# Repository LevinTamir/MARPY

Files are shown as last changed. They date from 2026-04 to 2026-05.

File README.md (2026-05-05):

<p align="center">
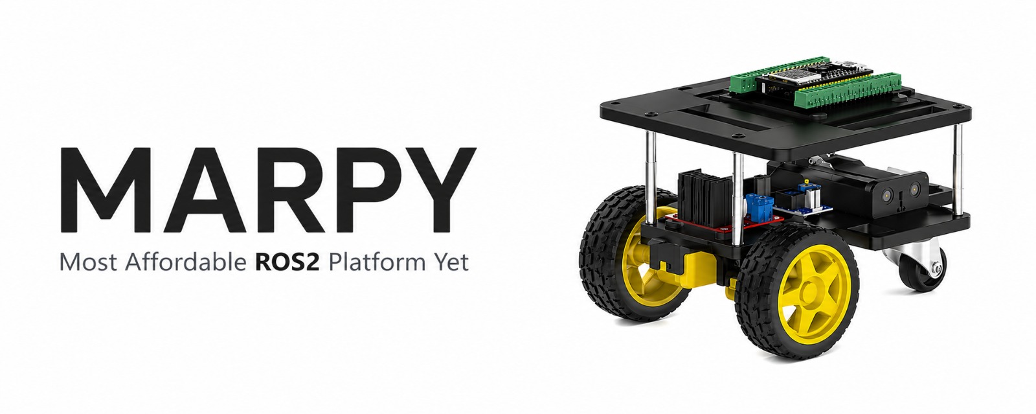
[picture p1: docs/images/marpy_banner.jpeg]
MARPY - Most Affordable ROS2 Platform Yet
  
</p>

<div align="center">

   

</div>

A cheap, open-source, 3D-printed differential-drive robot designed for beginners who want to learn ROS2 with real hardware.

---

## Requirements

- Ubuntu 24.04
- ROS2 Jazzy (or Docker)
- PlatformIO (for flashing the ESP32)
- A 2.4 GHz WiFi network the PC and the ESP32 boards can both join. A mobile phone hotspot works well (verified on iOS); the ESP32 does not support 5 GHz, so make sure the hotspot is on 2.4 GHz.

## Quick Start

### 1. Clone the workspace

```bash
git clone https://github.com/LevinTamir/MARPY.git marpy_ws
cd marpy_ws
```

### 2. Build the robot

Follow the guides in order:

| Step | Guide | Description |
|---|---|---|
| 1 | [Bill of Materials](docs/bom.md) | Buy the parts (< 50$) |
| 2 | [Assembly Instructions](docs/assembly.md) | Build the robot |
| 3 | [Wiring Guide](docs/wiring.md) | Connect all the electronics |
| 4 | [Firmware Setup](docs/firmware-setup.md) | Flash the ESP32 with micro-ROS |
| 5 | [ROS2 Setup](docs/ros2-setup.md) | Set up your PC and start driving! |
| 6 | [Simulation](docs/simulation.md) | Run MARPY in Gazebo (no hardware needed) |

### 3. Drive!

```bash
# Terminal 1: Start the micro-ROS agent
docker run -it --rm --net=host microros/micro-ros-agent:jazzy udp4 --port 8888 -v6

# Terminal 2: Launch the real robot (robot_state_publisher, odometry, RViz)
ros2 launch marpy_bringup real.launch.py

# Terminal 3: Drive with keyboard teleop
sudo apt install ros-jazzy-teleop-twist-keyboard
ros2 run teleop_twist_keyboard teleop_twist_keyboard
```

## Demos

**Real robot:**

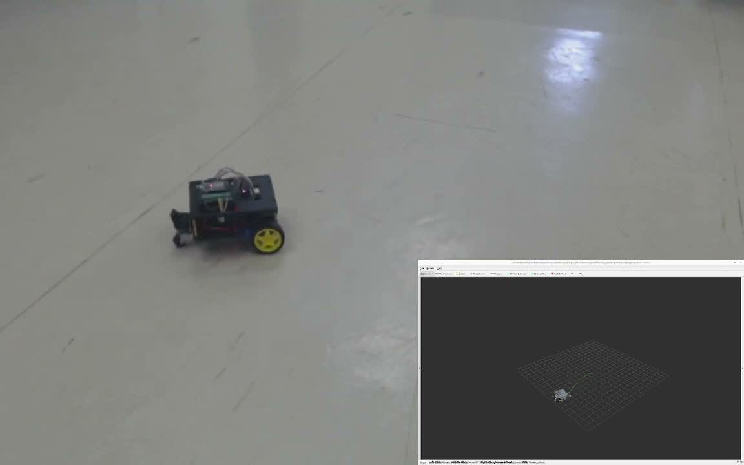
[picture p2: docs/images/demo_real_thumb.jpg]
MARPY real robot demo (https://youtu.be/ZrNPOut3CuA)


**Simulation:**

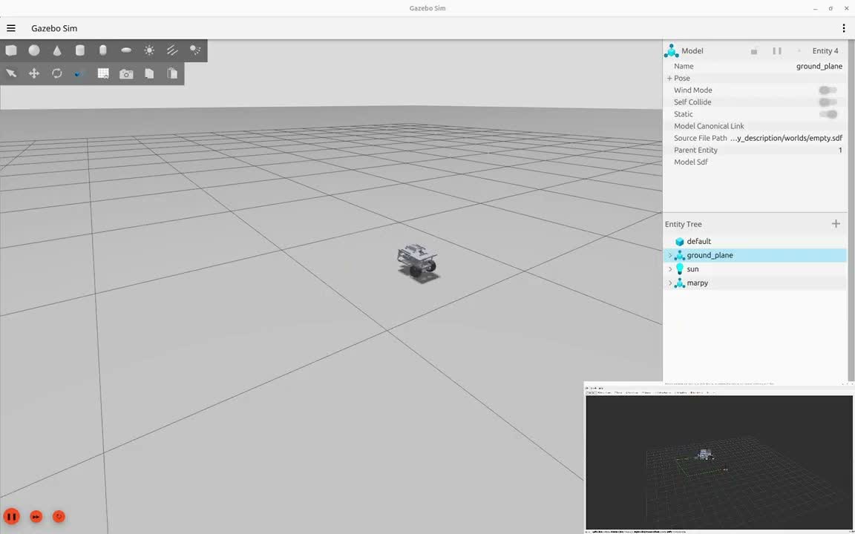
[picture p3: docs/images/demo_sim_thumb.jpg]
MARPY simulation demo (https://youtu.be/tEwZcNDOt3I)


## Repository Structure

```
marpy_ws/
├── README.md               ← You are here
├── docs/
│   ├── bom.md              ← Bill of materials + purchase links
│   ├── assembly.md         ← Step-by-step build guide
│   ├── wiring.md           ← Wiring diagram + pin tables
│   ├── firmware-setup.md   ← Flash the ESP32
│   ├── ros2-setup.md       ← ROS2 + micro-ROS agent setup
│   └── images/             ← Robot photos and diagrams
├── src/
│   ├── marpy_description/  ← URDF model + meshes + Gazebo worlds
│   ├── marpy_localization/ ← Wheel odometry + path tracking
│   └── marpy_bringup/      ← Launch files (sim + real)
├── docker/
│   ├── docker-compose.yml  ← micro-ROS agent + dev container
│   ├── Dockerfile          ← ROS2 Jazzy dev environment
│   └── entrypoint.sh
└── .github/workflows/      ← CI/CD pipeline
```

## Firmware Repositories

The ESP32 firmware lives in two separate repos:

- **[marpy_firmware](https://github.com/LevinTamir/marpy_firmware)** - PlatformIO project for the ESP32 drive controller: micro-ROS, motor control, encoder reading, and IMU.
- **[marpy_cam_firmware](https://github.com/LevinTamir/marpy_cam_firmware)** *(optional)* - PlatformIO project for the ESP32-CAM: serves an MJPEG stream over HTTP, republished as `sensor_msgs/Image` by the `marpy_cam_bridge` node.

## Contributing

Contributions are welcome! If you build a MARPY robot, open an issue with photos so everyone can see it.

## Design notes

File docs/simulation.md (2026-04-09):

# Simulation

Run MARPY in Gazebo Ignition without any hardware. The simulation uses the same `/cmd_vel` and `/joint_states` topics as the real robot, so teleop and odometry work identically.

## Prerequisites

Install the following ROS2 Jazzy packages (Ubuntu 24.04):

```bash
sudo apt update
sudo apt install -y \
  ros-jazzy-ros-gz-sim \
  ros-jazzy-ros-gz-bridge \
  ros-jazzy-robot-state-publisher \
  ros-jazzy-xacro \
  ros-jazzy-rviz2 \
  ros-jazzy-teleop-twist-keyboard
```

Build the workspace:

```bash
cd ~/marpy_ws
colcon build --symlink-install
source install/setup.bash
```

## Launch the Simulation

The `sim.launch.py` file starts Gazebo, RViz, and the odometry node in one command:

```bash
ros2 launch marpy_bringup sim.launch.py
```

This launches:
- **Gazebo Ignition** with the MARPY robot spawned in an empty world
- **RViz** for visualization (TF, robot model, odometry path)
- **Odometry node** computing wheel odometry from `/joint_states`

## Drive the Robot

In a separate terminal:

```bash
source ~/marpy_ws/install/setup.bash
ros2 run teleop_twist_keyboard teleop_twist_keyboard
```

Use the keyboard to drive. You should see:
- The robot moving in Gazebo
- The odometry path (`/odom_path`) drawing in RViz
- The TF tree updating in real time

## Visualize the Odometry Path in RViz

If the path is not already visible in RViz:

1. Click **Add** in the Displays panel
2. Select **By topic** → `/odom_path` → **Path**
3. Click **OK**

The path will draw the route the robot has traveled in the odom frame.

## View the URDF Model Only

To inspect the robot model in RViz without Gazebo:

```bash
ros2 launch marpy_description display.launch.py
```

## Custom Worlds

Pass a custom world file:

```bash
ros2 launch marpy_bringup sim.launch.py world_name:=my_world
```

World files are located in `src/marpy_description/worlds/` (SDF format).

## Troubleshooting

**Gazebo doesn't start or hangs:**
```bash
pkill -9 -f "gz sim|rviz2|robot_state_publisher|parameter_bridge"
```
Then relaunch.

**Robot doesn't move with teleop:**
- Make sure the teleop terminal is focused (it reads keypresses)
- Check that the Gazebo bridge is running: `ros2 topic list` should show `/cmd_vel`

**No odometry path in RViz:**
- Verify the odometry node is running: `ros2 node list` should show `/odometry_node`
- Check the topic: `ros2 topic echo /odom_path --once`

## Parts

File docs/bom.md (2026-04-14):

# Bill of Materials (BOM)

Everything you need to build your own MARPY robot. Total cost is approximately **$40-55 USD** depending on what you already have.

## Electronics

| # | Component | Qty | Est. Price | Link |
|---|---|-----|---|---|
| 1 | ESP32 DevKit V1 (30-pin) with Screw Terminal Breakout Board | 1 | ~$10 | [Amazon](https://www.amazon.com/dp/B0BNQ8VQDX) |
| 2 | L298N Dual H-Bridge Motor Driver | 1 | ~$3 | [Amazon](https://a.co/d/04wIWBpv) |
| 3 | TT Encoder Motor (6V DC Gear Motor with Hall Encoder) | 2 | ~$12 | [Amazon](https://www.amazon.com/dp/B0GS97898M) |
| 4 | 65mm TT Motor Wheels | 2 | ~$3 | [Amazon](https://www.amazon.com/dp/B0CG1C7T8J) |
| 5 | Low Profile Plastic Caster Wheel (1") | 1 | ~$3 | [Amazon](https://a.co/d/03JeFDlU) |
| 6 | 18650 Li-Ion Battery (3.7V, 2600mAh+) | 2 | ~$5 | [Amazon](https://www.amazon.com/dp/B0FP2DPJK7) |
| 7 | 2S 18650 Battery Holder with Switch | 1 | ~$3 | [Amazon](https://www.amazon.com/dp/B09ZPCX9VD) |
| 8 | LM2596S Adjustable DC-DC Buck Converter (7-28V to 5V) | 1 | ~$2 | [Amazon](https://a.co/d/05IxwOWH) |
| 9 | MPU6050 IMU (6-axis accelerometer + gyroscope) | 1 | ~$2 | [Amazon](https://www.amazon.com/dp/B00LP25V1A) |
| 10 | Jumper Wires | 1 kit | ~$3 | [Amazon](https://www.amazon.com/dp/B077NH83CJ) |
| 11 | Micro-USB Cable (for flashing ESP32) | 1 | ~$2 | [Amazon](https://www.amazon.com/dp/B013G4EAEI) |
| (optional) | ESP32-CAM with OV2640 Camera | 1 | ~$9 | [AliExpress](https://www.aliexpress.com/item/1005006341099716.html) |

## Hardware / Fasteners

| # | Component | Qty | Est. Price | Link |
|---|---|-----|---|---|
| 13 | M3x24 screws | 4 | ~$2 | See note below |
| 14 | M3x20 screws | 2 | ~$1 | See note below |
| 15 | M3x16 screws | 2 | ~$1 | See note below |
| 16 | M3x12 screws | 8 | ~$1 | See note below |
| 17 | M3x8 screws | 14 | ~$1 | See note below |
| 18 | M3x6 flat head screws | 2 | ~$1 | See note below |
| 19 | M3 nuts | 10 | ~$1 | See note below |
| 20 | M3 shims | 4 | ~$1 | See note below |
| 21 | M3x12 standoffs (female-male) | 4 | ~$2 | See note below |
| 22 | M3x40 standoffs (female-female) | 4 | ~$2 | [Amazon](https://a.co/d/03zlcVNa) |

> **Note:** Instead of buying each screw size individually, consider getting an **M3 hardware kit** that includes screws, nuts, standoffs, and washers in various sizes.

## 3D Printed Parts

| # | Part | File | Qty | Material |
|---|---|---|-----|---|
| 23 | Base Plate (bottom deck) | `Marpy_base_plate.STL` | 1 | PLA/PETG |
| 24 | Top Plate (electronics deck) | `Marpy_top_plate.STL` | 1 | PLA/PETG |
| 25 | Left Motor Mount | `Marpy_left_TT_motor_mount.STL` | 1 | PLA/PETG |
| 26 | Right Motor Mount | `Marpy_right_TT_motor_mount.STL` | 1 | PLA/PETG |
| 27 | On/Off Switch Mount | `Marpy_on_off_switch_mount.STL` | 1 | PLA/PETG |
| 28 | Camera Mount | `Marpy_cam_mount.STL` | 1 | PLA/PETG |
| 29 | ESP32-CAM Case | `ESP32_cam_case.stl` | 1 | PLA/PETG |
| 30 *(optional)* | ESP32-CAM Case (GoPro mount) | [Printables](https://www.printables.com/model/837615-esp32-cam-case-with-gopro-mount) | 1 | PLA/PETG |

> **Note:** STL files for all printed parts are available on [MakerWorld](https://makerworld.com/en/models/2655868-marpy#profileId-2936800). The optional [ESP32-CAM GoPro case](https://www.printables.com/model/837615-esp32-cam-case-with-gopro-mount) can be used with the camera mount adapter included in the MakerWorld files. Print at 0.2mm layer height, 20%+ infill. PLA works fine for indoor use.

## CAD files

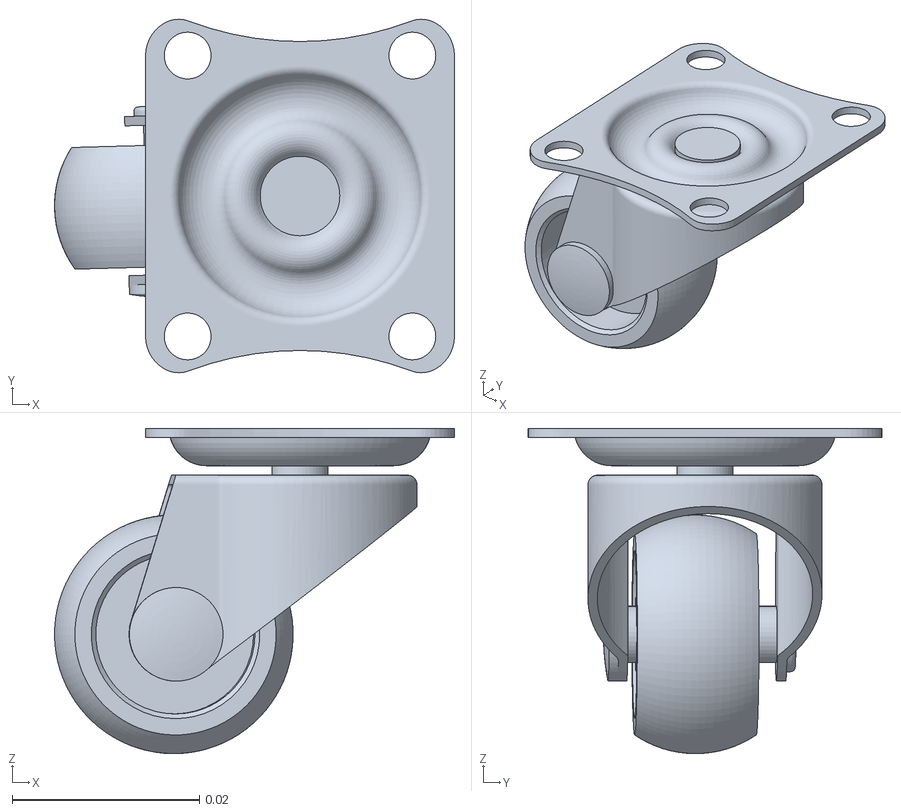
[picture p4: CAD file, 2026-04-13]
src/marpy_description/meshes/caster_wheel.STL
0.0427 x 0.0378 x 0.0347

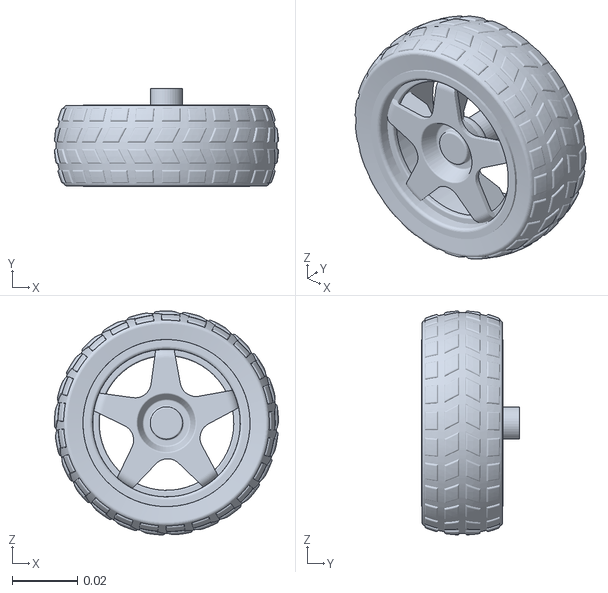
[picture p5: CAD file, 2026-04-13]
src/marpy_description/meshes/right_wheel.STL
0.0689 x 0.03 x 0.0689

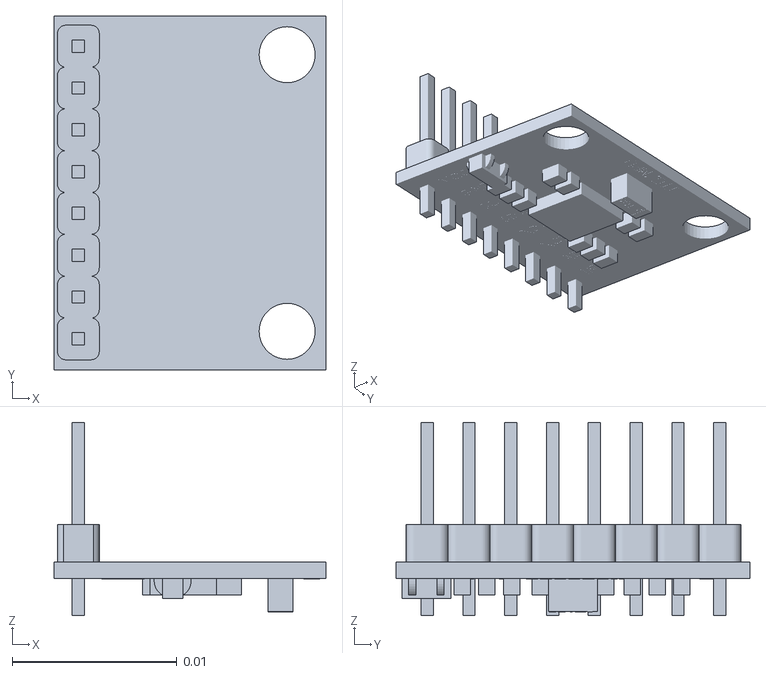
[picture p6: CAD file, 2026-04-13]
src/marpy_description/meshes/imu_link.STL
0.0165 x 0.0215 x 0.0117

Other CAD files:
src/marpy_description/meshes/left_wheel.STL

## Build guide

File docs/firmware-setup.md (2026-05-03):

# Firmware Setup (ESP32)

This guide walks you through flashing the micro-ROS base firmware (drive controller) onto the ESP32. Make sure you've completed the [Assembly](assembly.md) and [Wiring](wiring.md) first.

The MARPY firmware lives in two repos, each a self-contained PlatformIO project:

- [marpy_firmware](https://github.com/LevinTamir/marpy_firmware) (this guide): ESP32 drive controller, publishes `/joint_states` and `/imu`, subscribes to `/cmd_vel`.
- [marpy_cam_firmware](https://github.com/LevinTamir/marpy_cam_firmware): optional ESP32-CAM vision firmware that serves an MJPEG HTTP stream. See its README for setup; it does not use micro-ROS.

## What is PlatformIO?

[PlatformIO](https://platformio.org/) is a development platform for embedded systems. Think of it as a smarter replacement for the Arduino IDE - it handles board definitions, libraries, and build toolchains automatically. We use it to compile the micro-ROS firmware and flash it onto the ESP32.

The easiest way to use it is through the **VS Code extension**:

1. Open VS Code
2. Go to the Extensions tab (Ctrl+Shift+X)
3. Search for **"PlatformIO IDE"** and install it
4. Wait for it to finish setting up (it downloads toolchains in the background, this can take a few minutes the first time)
5. You'll see a new PlatformIO icon (alien head) in the left sidebar when it's ready

## Prerequisites

- [PlatformIO IDE](https://platformio.org/install/ide?install=vscode) extension in VS Code
- USB cable connected to the ESP32
- Your WiFi network name and password

## 1. Clone the Firmware

```bash
git clone https://github.com/LevinTamir/marpy_firmware.git
cd marpy_firmware
```

## 2. Configure WiFi and Agent IP

Create your private config file from the template:

```bash
cp include/wifi_config.h.example include/wifi_config.h
```

Edit `include/wifi_config.h` with your network details:

```cpp
static char WIFI_SSID[] = "YOUR_WIFI_SSID";        // your Wi-Fi network name
static char WIFI_PSK[]  = "YOUR_WIFI_PASSWORD";     // your Wi-Fi password
IPAddress AGENT_IP(192, 168, 1, 100);               // your PC's IP address
uint16_t AGENT_PORT = 8888;                         // micro-ROS agent port
```

### Finding your network details

**WiFi SSID** - the name of the network your PC is connected to:
```bash
nmcli -t -f active,ssid dev wifi | grep '^yes' | cut -d: -f2
```

**PC IP address** - this is what the ESP32 will connect to:
```bash
hostname -I | awk '{print $1}'
```

You can also find both from the network settings GUI: Settings > Wi-Fi > click the gear icon on your connected network. The IPv4 address is your `AGENT_IP`.

**WiFi password** - if you forgot it, you can retrieve the saved password:
```bash
nmcli -s -g 802-11-wireless-security.psk connection show "YOUR_SSID"
```

**Quick check** - verify everything in one command:
```bash
echo "SSID: $(nmcli -t -f active,ssid dev wifi | grep '^yes' | cut -d: -f2)"
echo "IP:   $(hostname -I | awk '{print $1}')"
```

> **Important:** The ESP32 and your PC must be on the **same WiFi network** (2.4 GHz). The ESP32 does not support 5 GHz networks.
>
> `wifi_config.h` is git-ignored - your credentials never get pushed to GitHub.

## 3. Build and Flash

### Using VS Code (recommended)

1. Open the `marpy_firmware` folder in VS Code (`File > Open Folder`)
2. PlatformIO detects the `platformio.ini` file at the repo root and configures the project automatically.
3. Connect the ESP32 via USB
4. Click the **Upload** button (right arrow icon) in the bottom status bar.
5. Wait for it to compile and flash. You'll see `SUCCESS` in the terminal when done

#### Optional: VS Code Python IntelliSense

The firmware repo's `.vscode/settings.json` references `${env:MARPY_WS}` so VS Code's Python analyzer can find ROS2 message types from your workspace install. If you ever edit ROS2 Python nodes alongside the firmware, point `MARPY_WS` at wherever you cloned the workspace and add it to your shell rc:

```bash
echo 'export MARPY_WS=/path/to/your/marpy_ws' >> ~/.bashrc
```

No effect on flashing or C++ IntelliSense, this only affects Python autocomplete for ROS2 messages.

### Using the CLI

If you prefer the terminal (run from the firmware repo root):
```bash
pio run --target upload
```

## 4. Monitor Serial Output

```bash
pio device monitor -b 115200
```

You should see:
```
WiFi connected
Waiting for micro-ROS agent...
micro-ROS agent connected!
```

If it stays on "Waiting for micro-ROS agent..." - make sure the agent is running on your PC (see [ROS2 Setup](ros2-setup.md)).

## Troubleshooting

| Problem | Solution |
|---|---|
| Upload fails | Hold the **BOOT** button on ESP32 while uploading |
| WiFi won't connect | Double-check SSID/password in `include/wifi_config.h`, ensure 2.4GHz network (ESP32 doesn't support 5GHz) |
| Agent not found | Verify PC IP address, check firewall (`sudo ufw allow 8888/udp`) |
| Motors don't spin | Re-check the [Wiring Guide](wiring.md). Usually a swapped IN1/IN2, missing common ground, or the ENA/ENB jumpers still in place |

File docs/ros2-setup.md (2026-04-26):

# ROS2 Setup Guide

Complete setup guide for running MARPY on Ubuntu 24.04 with ROS2 Jazzy.

## Option A: Docker (Recommended for Beginners)

Docker is the easiest way to get started - no ROS2 installation needed on your host machine.

### Prerequisites
- [Docker Engine](https://docs.docker.com/engine/install/ubuntu/)
- [Docker Compose](https://docs.docker.com/compose/install/)

### 1. Clone the Workspace

```bash
git clone https://github.com/LevinTamir/MARPY.git marpy_ws
cd marpy_ws
```

### 2. Start the Containers

This launches both the **micro-ROS agent** and the **ROS2 workspace** container:

```bash
cd docker
docker compose up -d
```

### 3. Enter the Workspace

```bash
docker exec -it marpy_ws bash
```

### 4. Build the Workspace

Inside the container:
```bash
colcon build --symlink-install
source install/setup.bash
```

### 5. Run Teleop

```bash
ros2 run teleop_control_node teleop_control
```

Now drive your robot with `i`, `j`, `k`, `l` keys!

---

## Option B: Native Installation

> This section assumes you already have **ROS2 Jazzy installed** on Ubuntu 24.04.
> If not, follow the [official installation guide](https://docs.ros.org/en/jazzy/Installation/Ubuntu-Install-Debs.html) first.

### 1. Clone and Build the Workspace

```bash
git clone https://github.com/LevinTamir/MARPY.git marpy_ws
cd marpy_ws
rosdep install --from-paths src --ignore-src -r -y
colcon build --symlink-install
source install/setup.bash
```

### 2. Run the micro-ROS Agent

The agent bridges the ESP32 (UDP over WiFi) to the ROS2 network.

**Using Docker (easiest):**
```bash
docker run -it --rm --net=host microros/micro-ros-agent:jazzy udp4 --port 8888 -v6
```

**Or install natively:**
```bash
sudo apt install ros-jazzy-micro-ros-agent
ros2 run micro_ros_agent micro_ros_agent udp4 --port 8888 -v6
```

### 3. Verify the Connection

Once the ESP32 is powered on and connected to WiFi, you should see it connect in the agent output.

> **If the agent log stays silent / ESP32 keeps printing "Waiting for micro-ROS agent..."**, press the **EN** (reset) button on the ESP32. Agent discovery only runs at boot, so if the ESP32 came up before the agent, a reset re-runs it. (BOOT is flash-mode, not reset.)

Then verify:

```bash
# List active topics
ros2 topic list
# Expected: /cmd_vel, /joint_states

# Check encoder data from ESP32
ros2 topic echo /joint_states

# Send a test velocity command
ros2 topic pub /cmd_vel geometry_msgs/msg/Twist "{linear: {x: 0.1}, angular: {z: 0.0}}" --once
```

### 4. Run Teleop

```bash
ros2 run teleop_control_node teleop_control
```

## Network Configuration

| Setting | Value |
|---|---|
| ESP32 WiFi | Must be same network as PC |
| Agent Port | 8888 (UDP) |
| ROS Domain ID | 0 (default) |
| Firewall | Allow UDP port 8888: `sudo ufw allow 8888/udp` |

## ROS2 Topics

| Topic | Type | Direction | Rate |
|---|---|---|---|
| `/cmd_vel` | `geometry_msgs/Twist` | PC -> ESP32 | On demand |
| `/joint_states` | `sensor_msgs/JointState` | ESP32 -> PC | 20 Hz |
| `/odom` | `nav_msgs/Odometry` | Odometry node | 20 Hz |
| `/odom_path` | `nav_msgs/Path` | Odometry node | 20 Hz |
| `/imu` | `sensor_msgs/Imu` | ESP32 -> PC | 50 Hz |

## Quick Reference

```bash
# Terminal 1: micro-ROS agent
docker run -it --rm --net=host microros/micro-ros-agent:jazzy udp4 --port 8888 -v6

# Terminal 2: RViz (robot visualization)
cd marpy_ws
source install/setup.bash
ros2 launch marpy_description display.launch.py

# Terminal 3: Teleop
cd marpy_ws
source install/setup.bash
ros2 run teleop_control_node teleop_control
```

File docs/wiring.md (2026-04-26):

# Wiring Guide

> [!CAUTION]
> **NEVER connect the ESP32 to your PC via USB while the robot's batteries are switched ON.** The battery power will back-feed through the ESP32's VIN into your computer's USB port. This can damage your PC, the ESP32, or both. **Always turn off the battery switch before plugging in a USB cable** for flashing firmware or any other reason. To be safe, you can **disconnect the ESP32 entirely** from the terminal board while flashing.

This guide covers all electrical connections for the MARPY robot. Make sure you've completed the [Assembly](assembly.md) first - all components should be physically mounted before wiring.

## Wiring Diagram

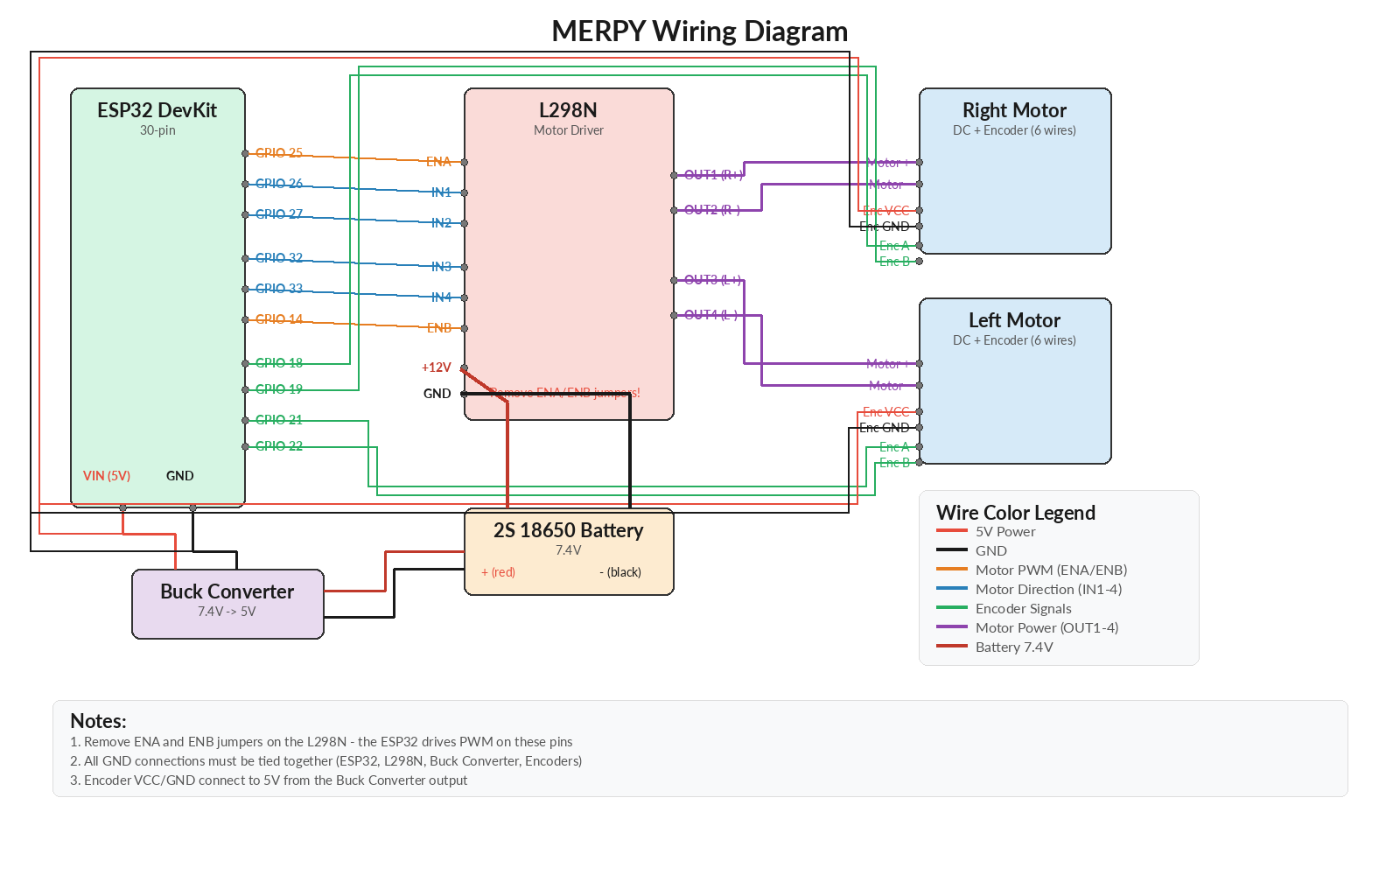
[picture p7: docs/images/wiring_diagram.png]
MARPY Wiring Diagram


## Full Schematic

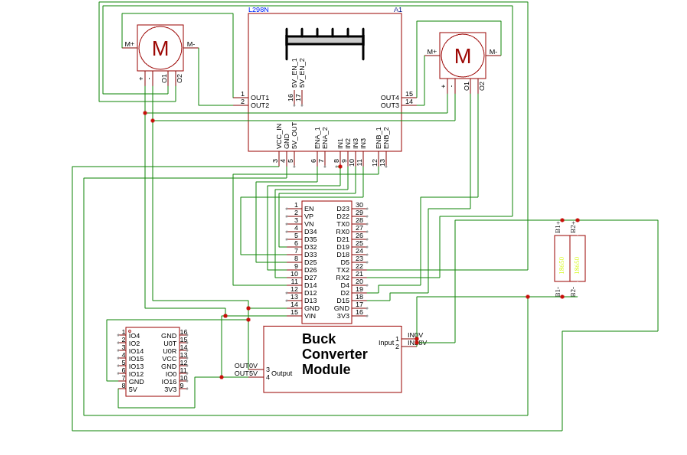
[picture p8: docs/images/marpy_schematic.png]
MARPY Schematic


## Step 1: Power Distribution

1. **Battery Pack** (2S 18650, ~7.4V) connects through the on/off switch to:
   - L298N `+12V` input (powers the motors directly)
   - Buck converter input

2. **Buck Converter** (7.4V -> 5V) connects to:
   - ESP32 `VIN` pin (5V)
   - Encoder VCC lines (5V)

3. **Ground:** All GND connections must be **common** - ESP32 GND, L298N GND, buck converter GND, encoder GND all tied together.

> **Tip:** Set the buck converter output to **5V** using a multimeter before connecting the ESP32.

## Step 2: Motor Control Wiring (ESP32 to L298N)

| ESP32 GPIO | L298N Pin | Function |
|---|---|---|
| GPIO 25 | ENA | Right motor speed (PWM) |
| GPIO 26 | IN1 | Right motor direction A |
| GPIO 27 | IN2 | Right motor direction B |
| GPIO 32 | IN3 | Left motor direction A |
| GPIO 33 | IN4 | Left motor direction B |
| GPIO 14 | ENB | Left motor speed (PWM) |

> **Important:** Remove the ENA and ENB jumpers on the L298N board. These pins must be driven by the ESP32 PWM, not tied to 5V.

## Step 3: Motor Wiring (L298N to Motors)

Each DC gear motor has 6 wires:

| Wire Color | Label | Connection |
|---|---|---|
| Red | M+ | L298N OUT1/OUT3 (motor power +) |
| Blue | M- | L298N OUT2/OUT4 (motor power -) |
| Green | VCC | 5V (encoder power) |
| Black | GND | GND (encoder ground) |
| Yellow | C1 | ESP32 GPIO - Encoder Channel A (see table below) |
| White | C2 | ESP32 GPIO - Encoder Channel B (see table below) |

> **Tip:** If a motor spins the wrong direction, swap its M+ (red) and M- (blue) wires at the L298N output. If an encoder counts in the wrong direction, swap its C1 (yellow) and C2 (white) channels.

## Step 4: Encoder Wiring

| Motor Wire | Color | ESP32 GPIO | Function |
|---|---|---|---|
| C1 | Yellow | GPIO 18 | Right encoder - Channel A |
| C2 | White | GPIO 19 | Right encoder - Channel B |
| VCC | Green | 5V (buck converter) | Right encoder power |
| GND | Black | GND | Right encoder ground |
| C1 | Yellow | GPIO 21 | Left encoder - Channel A |
| C2 | White | GPIO 22 | Left encoder - Channel B |
| VCC | Green | 5V (buck converter) | Left encoder power |
| GND | Black | GND | Left encoder ground |

## Step 5: IMU Wiring (MPU6050)

The MPU6050 IMU connects to the ESP32 via I2C. Since the default I2C pins (GPIO 21/22) are used by the encoders, we use GPIO 13 (SDA) and GPIO 15 (SCL).

| MPU6050 Pin | Connection |
|---|---|
| VCC | 3.3V (from ESP32 3V3 pin) |
| GND | GND (common ground) |
| SDA | ESP32 GPIO 13 |
| SCL | ESP32 GPIO 15 |

> **Important:** The MPU6050 runs on **3.3V**. Connect VCC to the ESP32's 3V3 pin, **not** 5V. AD0 and INT can be left unconnected (AD0 defaults to GND internally, giving I2C address 0x68).

## Pre-Flight Checklist

Before powering on, verify:

- [ ] L298N ENA/ENB jumpers **removed**
- [ ] All grounds connected together
- [ ] Buck converter output reads ~5V with a multimeter
- [ ] ESP32 powers on when battery is connected
- [ ] MPU6050 VCC connected to **3.3V** (not 5V)
- [ ] Motors are free to spin (wheels off the ground for first test)

## Next Step

With all wiring complete, proceed to the [Firmware Setup](firmware-setup.md) to flash micro-ROS onto the ESP32.

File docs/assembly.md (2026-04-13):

# Assembly Instructions

Step-by-step guide to physically build your MARPY robot. Once assembled, continue to the [Wiring Guide](wiring.md) to connect everything electrically.

## What You'll Need

- All parts from the [Bill of Materials](bom.md)
- 3D printed parts (Download the STLs from [MakerWorld](https://makerworld.com/en/models/2655868-marpy#profileId-2936800))
- Basic tools: screwdriver, hex key (Allen wrench)

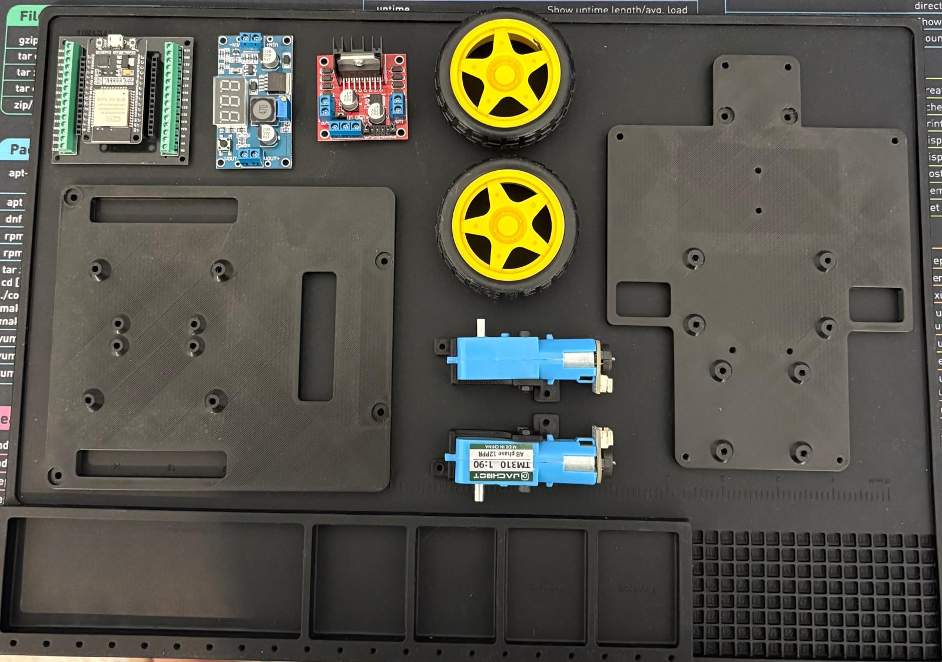
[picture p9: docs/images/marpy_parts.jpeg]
All parts laid out


## Step 1: Attach Motors to Motor Mounts

| Hardware | Qty |
|---|-----|
| Motor mounts (3D printed) | 2 |
| M3x24 screws | 4 |
| M3 nuts | 4 |

1. Slide each DC motor into its 3D-printed motor mount bracket.
2. Secure each motor with 2 screws and nuts.

<p>
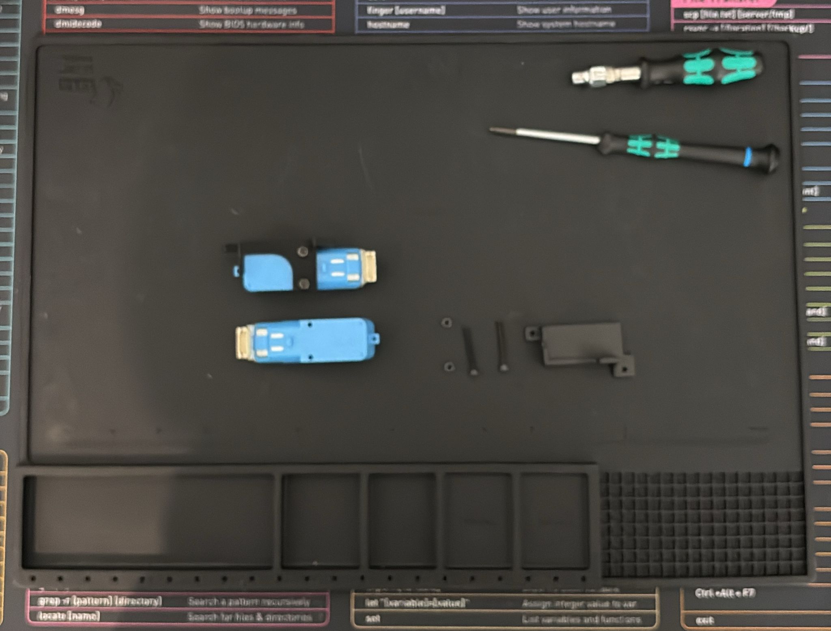
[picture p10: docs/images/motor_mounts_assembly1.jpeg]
Motor mount parts

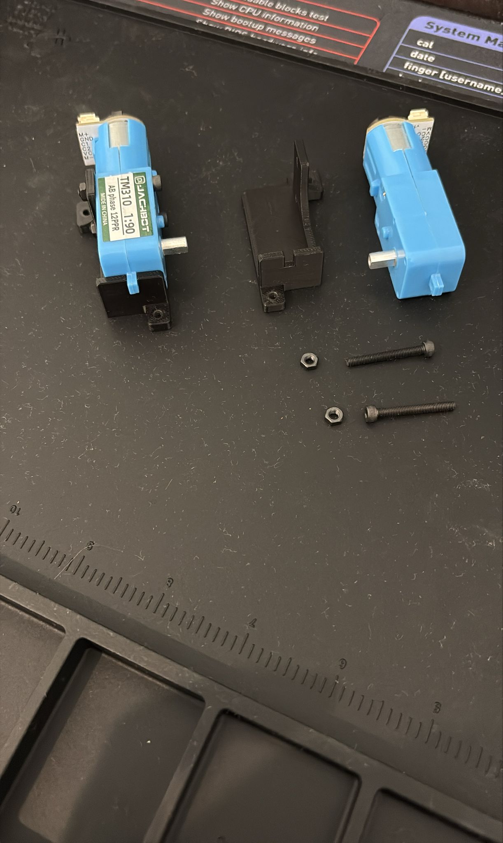
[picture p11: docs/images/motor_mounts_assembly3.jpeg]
Motor secured in mount

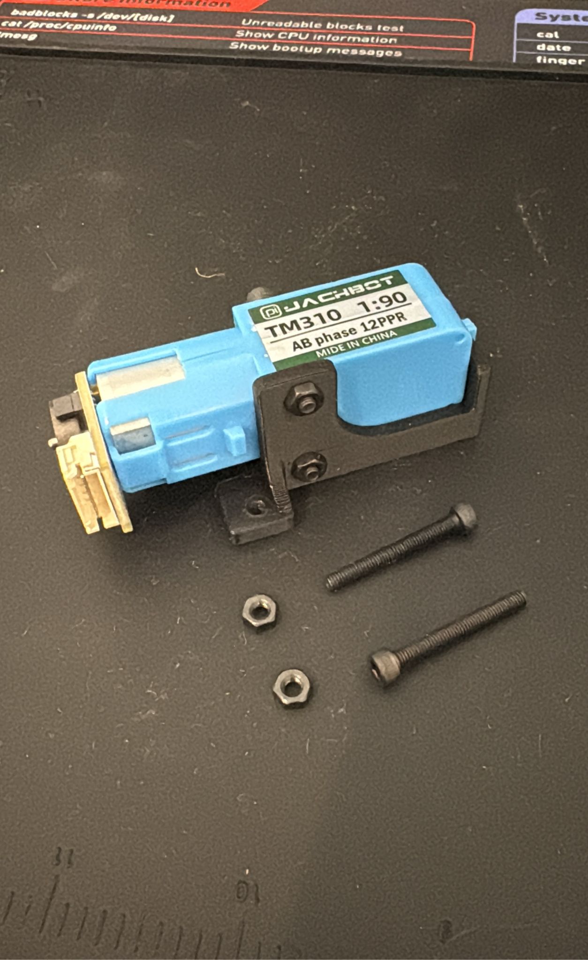
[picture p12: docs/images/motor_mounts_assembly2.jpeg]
Both motors with mounts

</p>

## Step 2: Assemble the On/Off Switch

| Hardware | Qty |
|---|-----|
| On/off switch | 1 |
| Switch mount (3D printed) | 1 |

1. Press-fit the on/off switch into the 3D-printed switch mount.

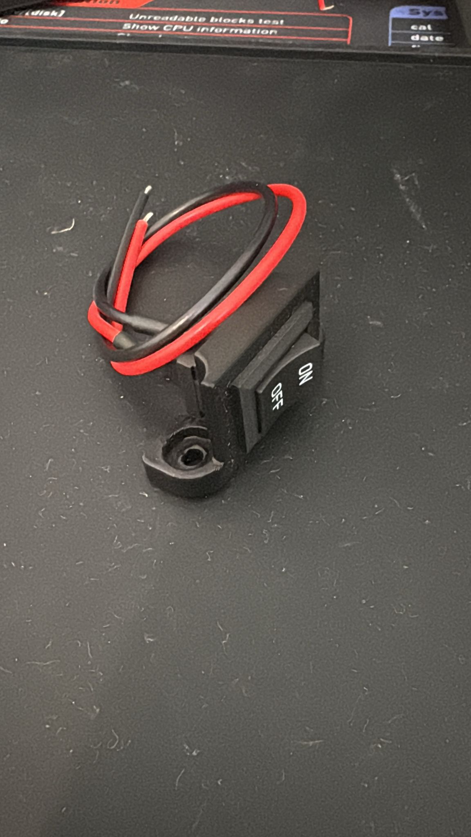
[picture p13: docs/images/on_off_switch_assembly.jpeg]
On/off switch in mount


## Step 3: Assemble the Caster Wheel

| Hardware | Qty |
|---|-----|
| Caster wheel | 1 |
| M3x12 standoffs (female-male) | 4 |
| M3 shims | 4 |
| M3 nuts | 4 |

1. Attach the caster wheel to its mounting plate using screws and nuts.
2. Screw the standoffs into the caster plate, these will later connect to the base plate.

<p>
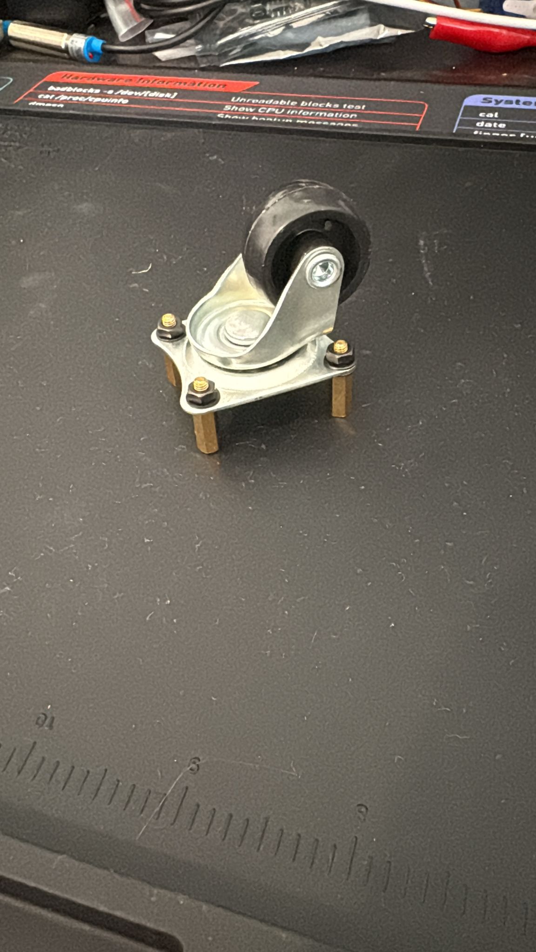
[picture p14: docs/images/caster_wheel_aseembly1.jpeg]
Caster wheel assembled

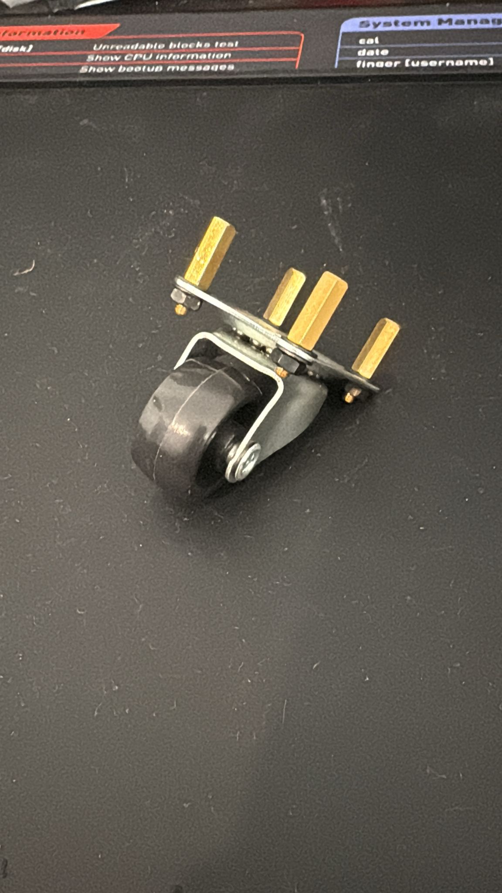
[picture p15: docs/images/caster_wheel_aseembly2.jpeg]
Caster wheel with standoffs

</p>

## Step 4: Assemble the Lower Chassis

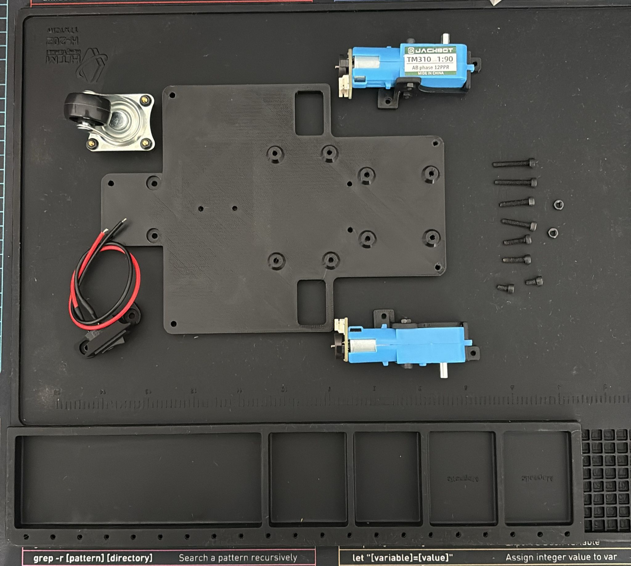
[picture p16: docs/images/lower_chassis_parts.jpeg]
Lower chassis parts laid out


### Step 4.1: Mount Motors to Base Plate

| Hardware | Qty |
|---|-----|
| M3x20 screws | 2 |
| M3x16 screws | 2 |
| M3 nuts | 2 |

1. Slide the motor mount brackets into the base plate slots from the bottom.
2. Secure each motor mount with the M3x16 screws and nuts.
3. Insert the M3x20 screws facing **upwards** through the base plate - no nuts needed, these will thread into the standoffs later.

<p>
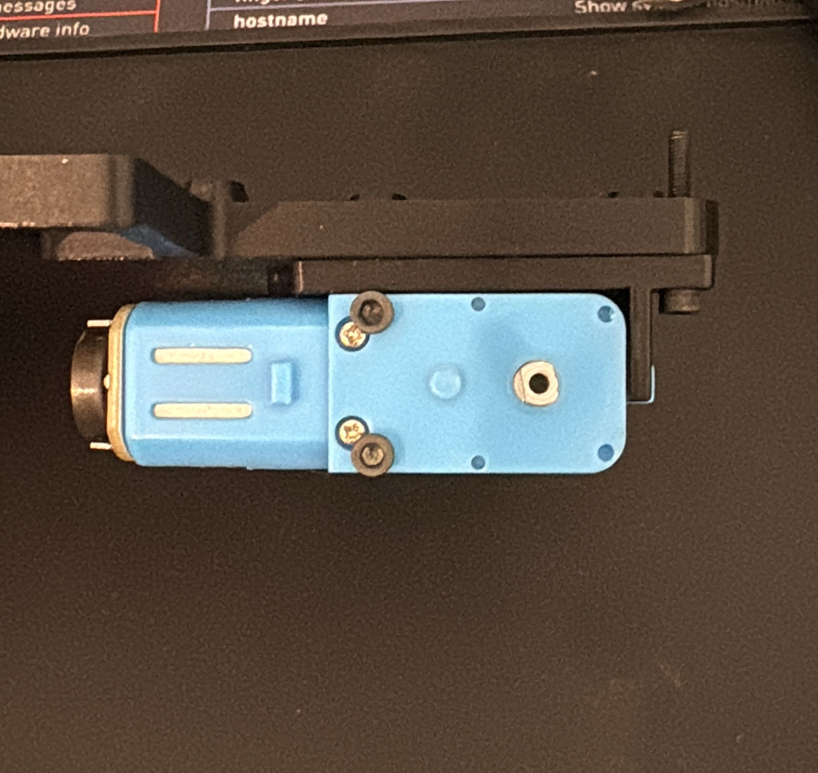
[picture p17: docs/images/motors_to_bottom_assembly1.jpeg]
Motor mounted to base plate

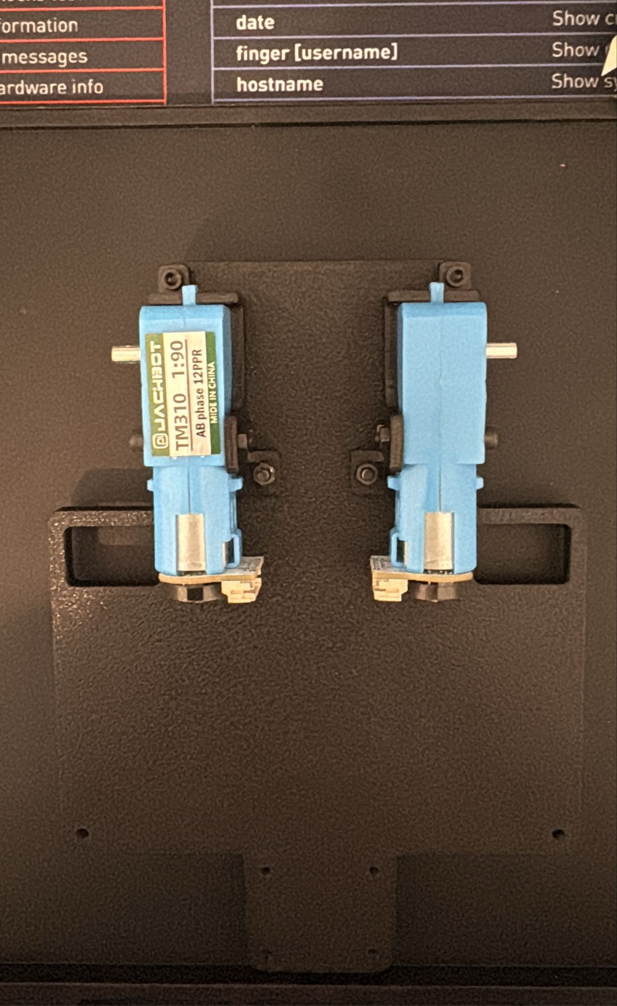
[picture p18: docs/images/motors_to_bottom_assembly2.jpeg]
Both motors mounted

</p>

### Step 4.2: Attach Caster and Switch to Base Plate

| Hardware | Qty |
|---|-----|
| M3x12 screws | 4 |

1. Screw the caster assembly and on/off switch to the base plate using the M3x12 screws.

<p>
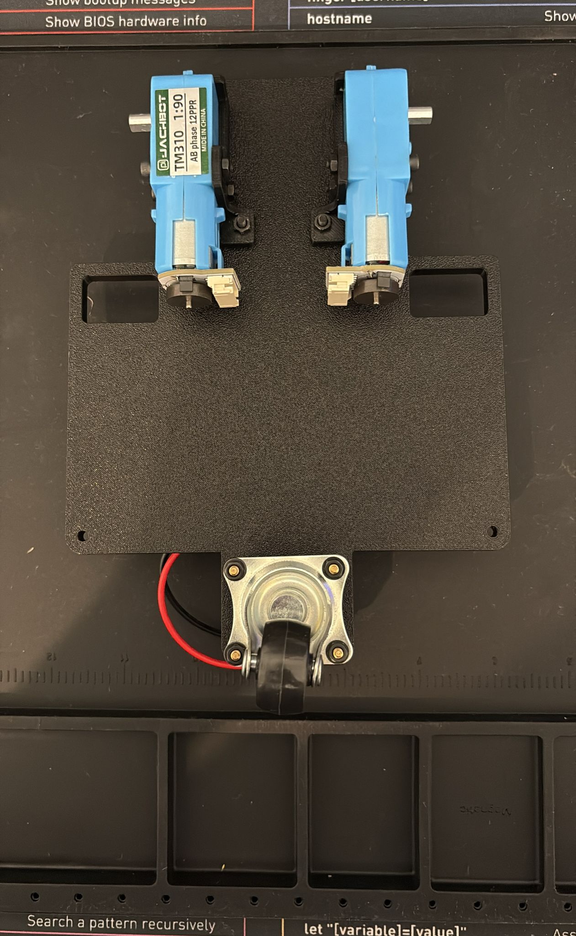
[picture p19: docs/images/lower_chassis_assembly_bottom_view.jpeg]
Lower chassis bottom view

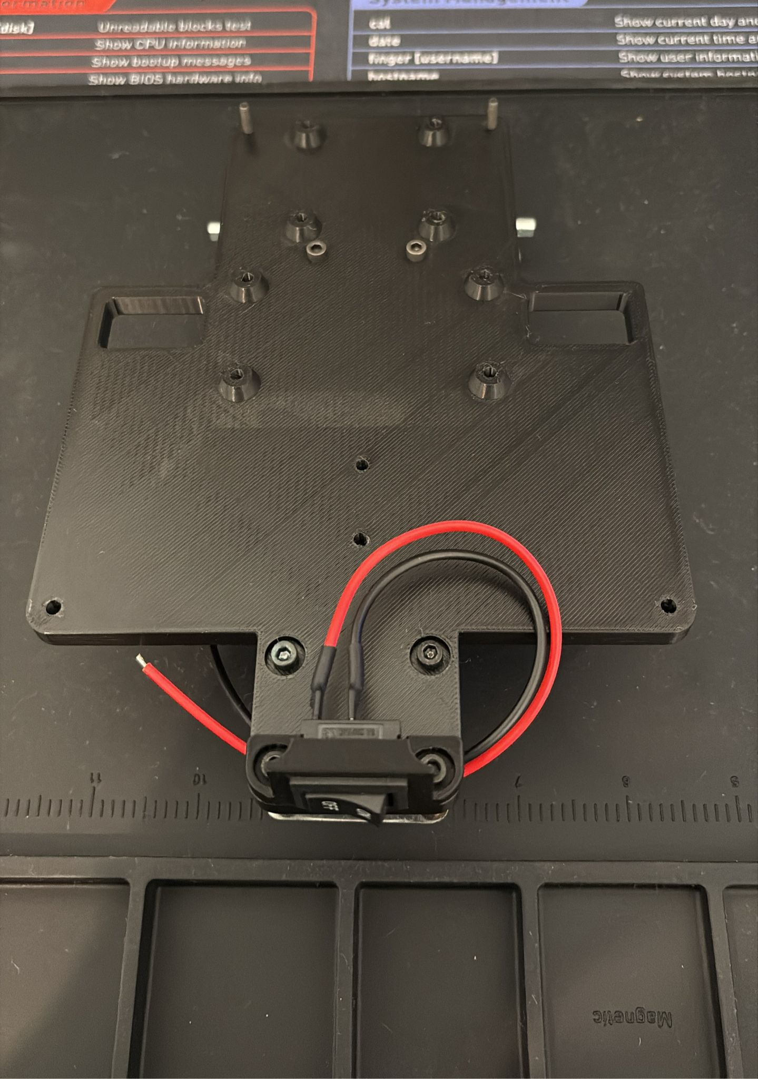
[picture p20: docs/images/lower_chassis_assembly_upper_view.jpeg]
Lower chassis top view

</p>

## Step 5: Mount the Electronics

| Hardware | Qty |
|---|-----|
| L298N motor driver | 1 |
| Battery holder (2S 18650) | 1 |
| Buck converter | 1 |
| M3x8 screws | 8 |
| M3x6 flat head screws (optional) | 2 |

Mount the electronic components onto the base plate. Wiring is covered in the [Wiring Guide](wiring.md) later.

1. Mount the **L298N motor driver** and **LM2596S buck converter** to the base plate using M3x8 screws. Match the orientation shown in the photos.
2. Attach the **battery holder** using M3x6 flat head screws (glue/double-sided tape is also possible)

<p>
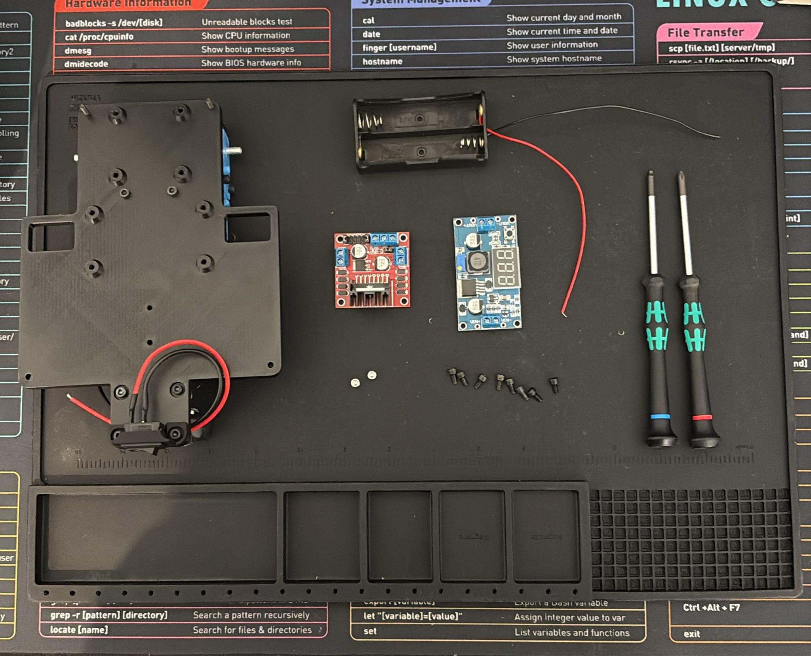
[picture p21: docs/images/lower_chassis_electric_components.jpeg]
Electronics components before mounting

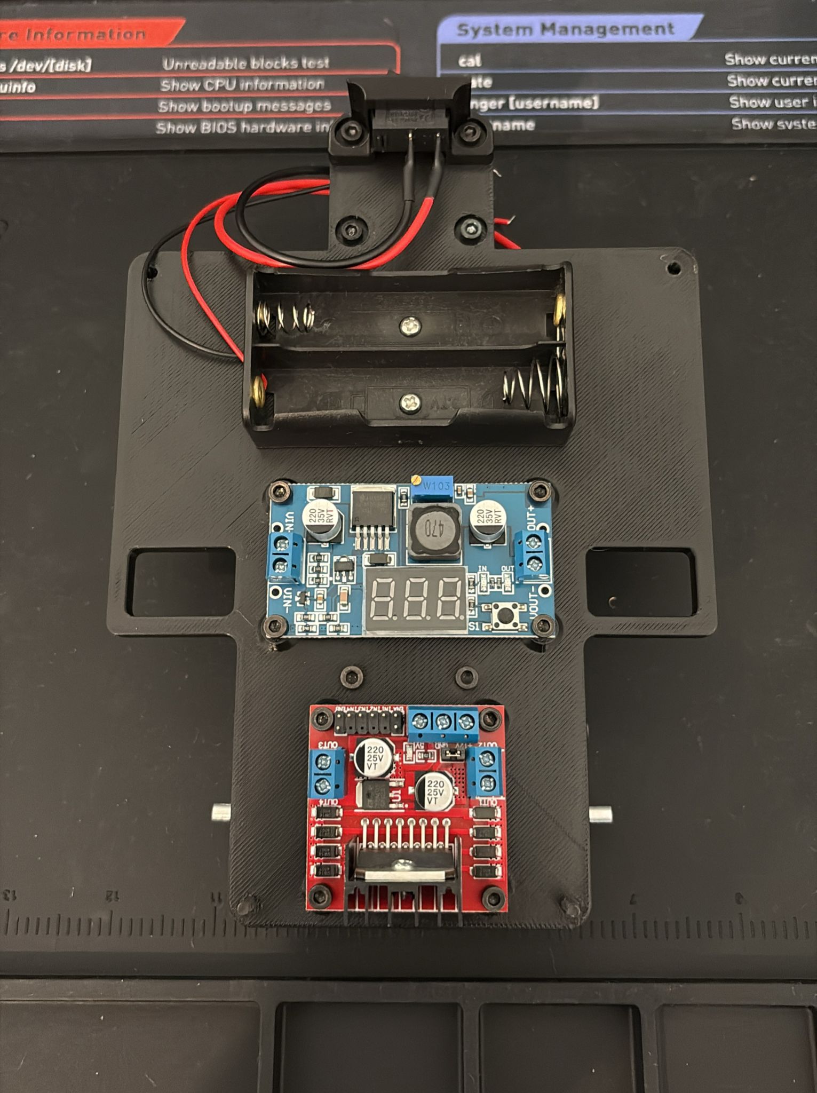
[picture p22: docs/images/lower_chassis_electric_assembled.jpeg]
Electronics mounted on base plate

</p>

## Step 6: Attach the Wheels

| Hardware | Qty |
|---|-----|
| TT motor wheels | 2 |

1. Press the yellow TT wheels onto the motor shafts.

<p>
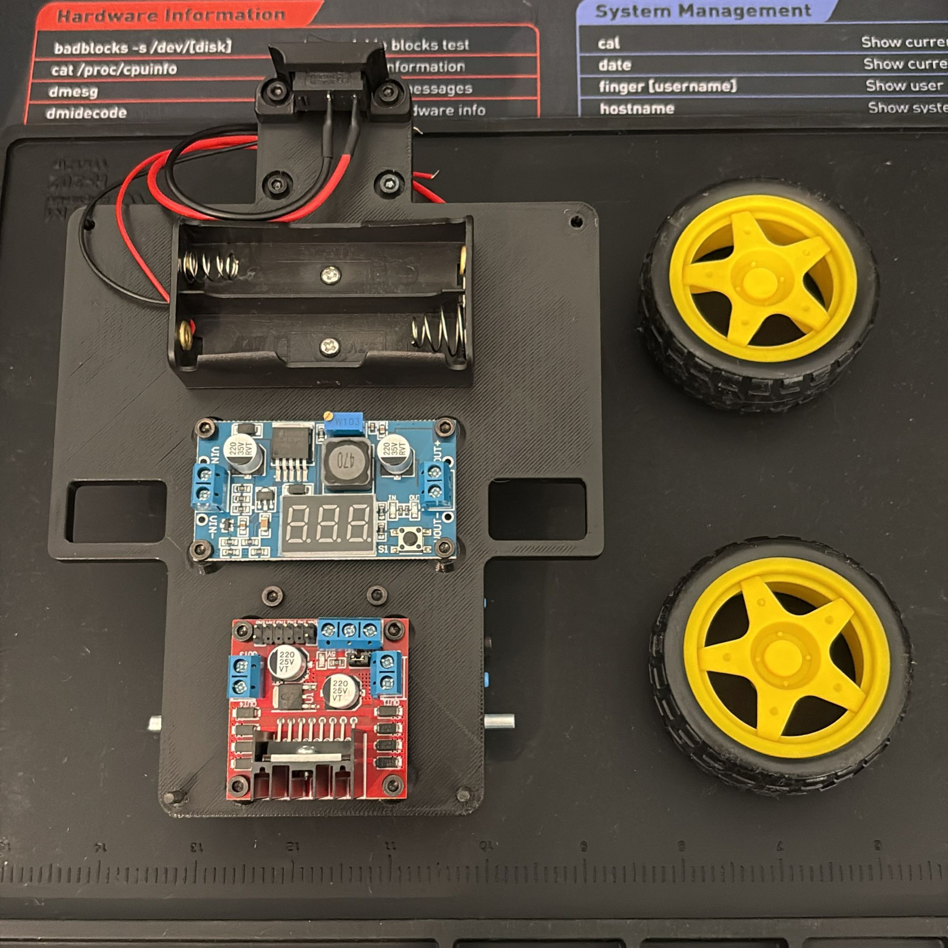
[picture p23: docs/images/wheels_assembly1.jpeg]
Wheels attached top view

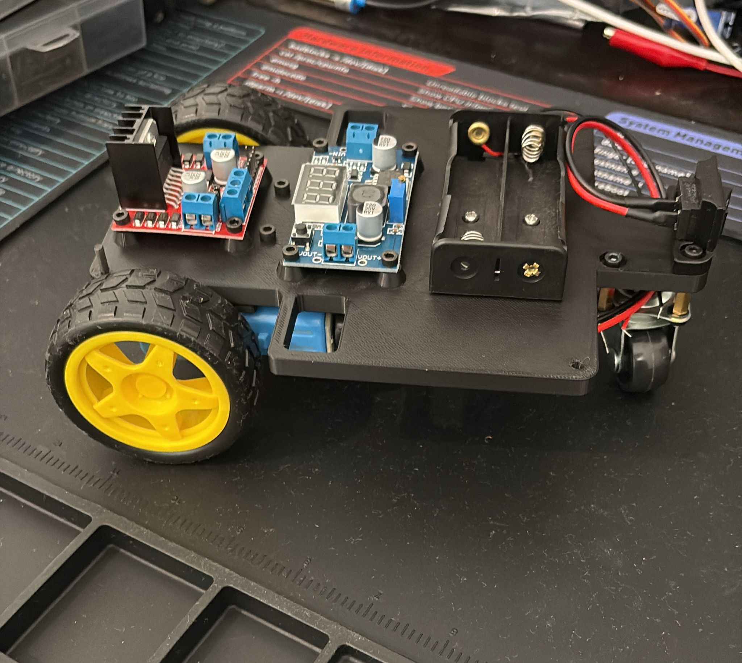
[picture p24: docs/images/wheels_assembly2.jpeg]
Wheels attached side view

</p>

## Step 7: Mount the ESP32 on Top Plate

| Hardware | Qty |
|---|-----|
| Top plate (3D printed) | 1 |
| ESP32 DevKit V1 | 1 |
| Screw terminal breakout board | 1 |
| M3x8 screws | 6 |

1. Mount the screw terminal breakout board onto the top plate using M3 screws.
2. Plug the ESP32 DevKit into the breakout board. Keep the USB port accessible for flashing and debugging.

<p>
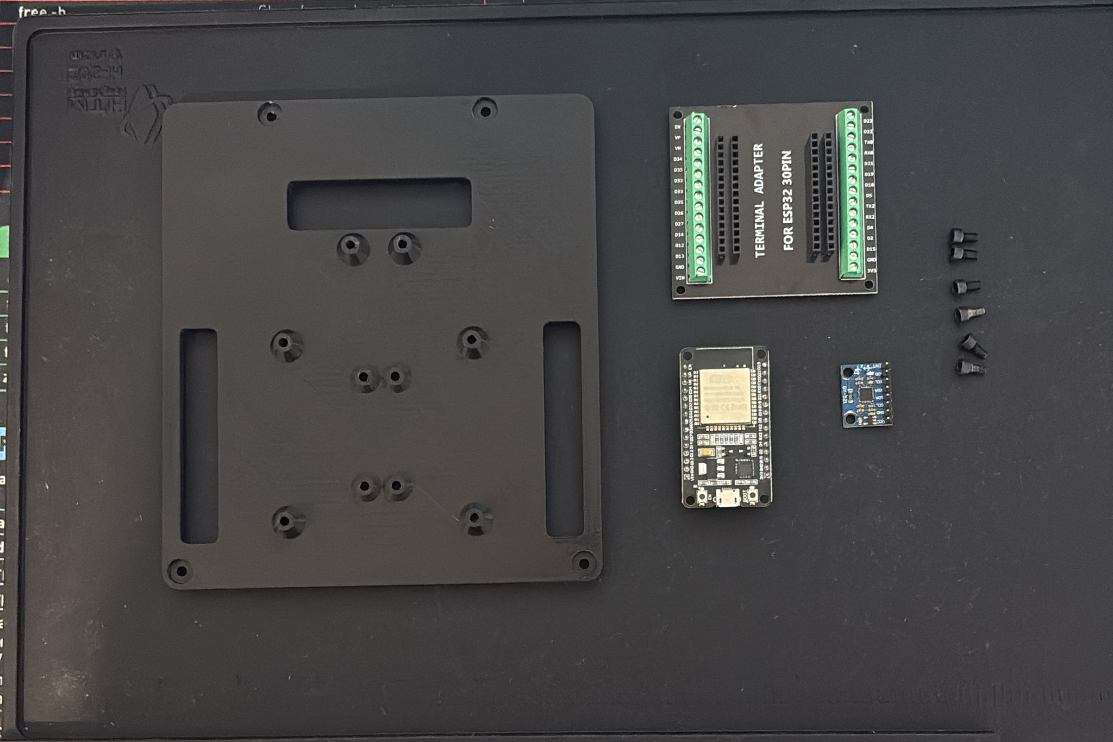
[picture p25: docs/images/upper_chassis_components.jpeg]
Top plate components

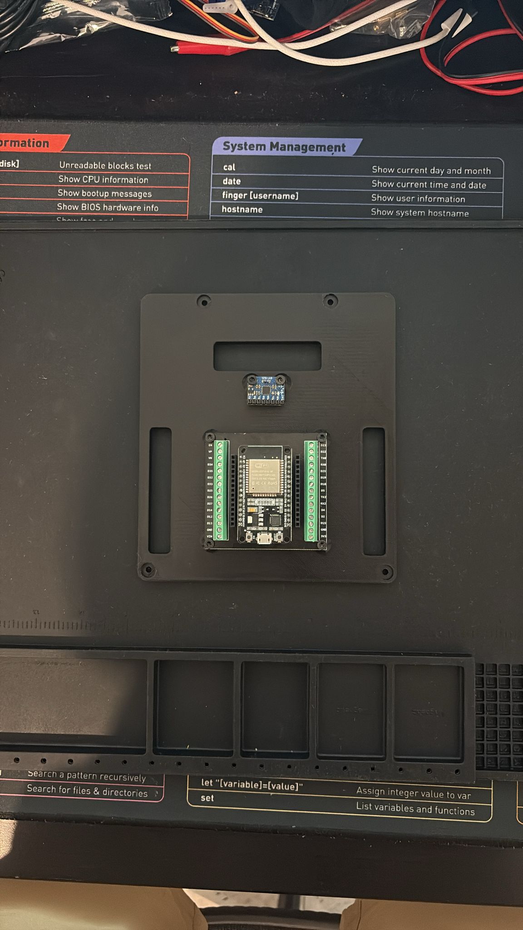
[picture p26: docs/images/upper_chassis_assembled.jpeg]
ESP32 mounted on top plate

</p>

## Step 8: Final Assembly

| Hardware | Qty |
|---|-----|
| M3x40 standoffs | 4 |
| M3x12 screws | 4 |

1. Screw the 4 standoff posts into the base plate corners.

<p>
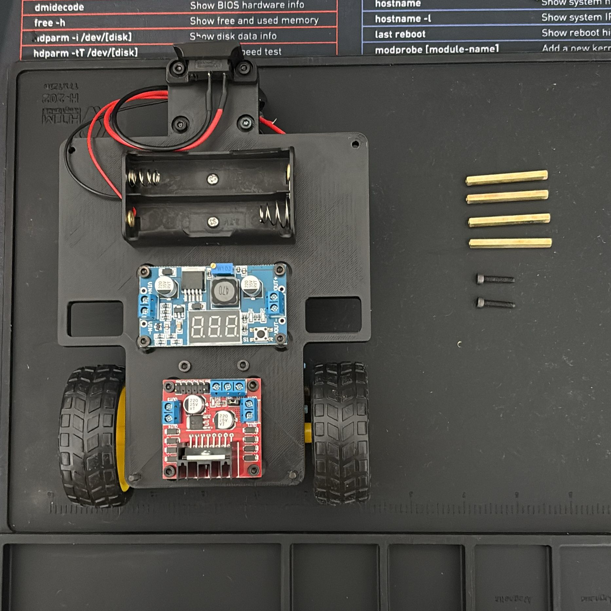
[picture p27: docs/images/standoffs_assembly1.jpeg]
Standoffs and screws

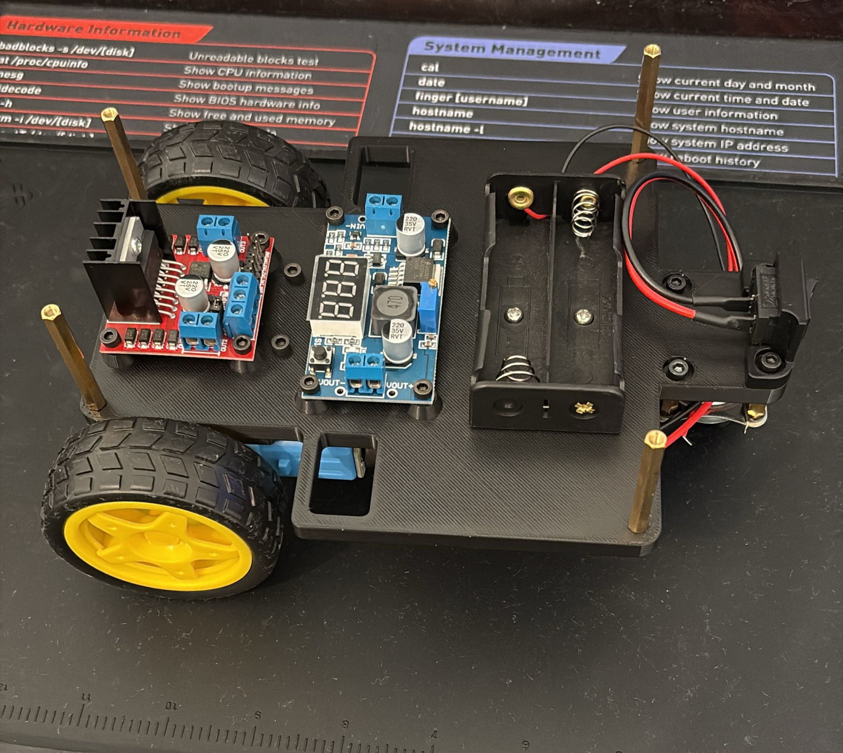
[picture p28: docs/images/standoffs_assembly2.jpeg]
Standoffs installed

</p>

2. Place the top deck assembly on the standoffs and secure with M3x12 screws.

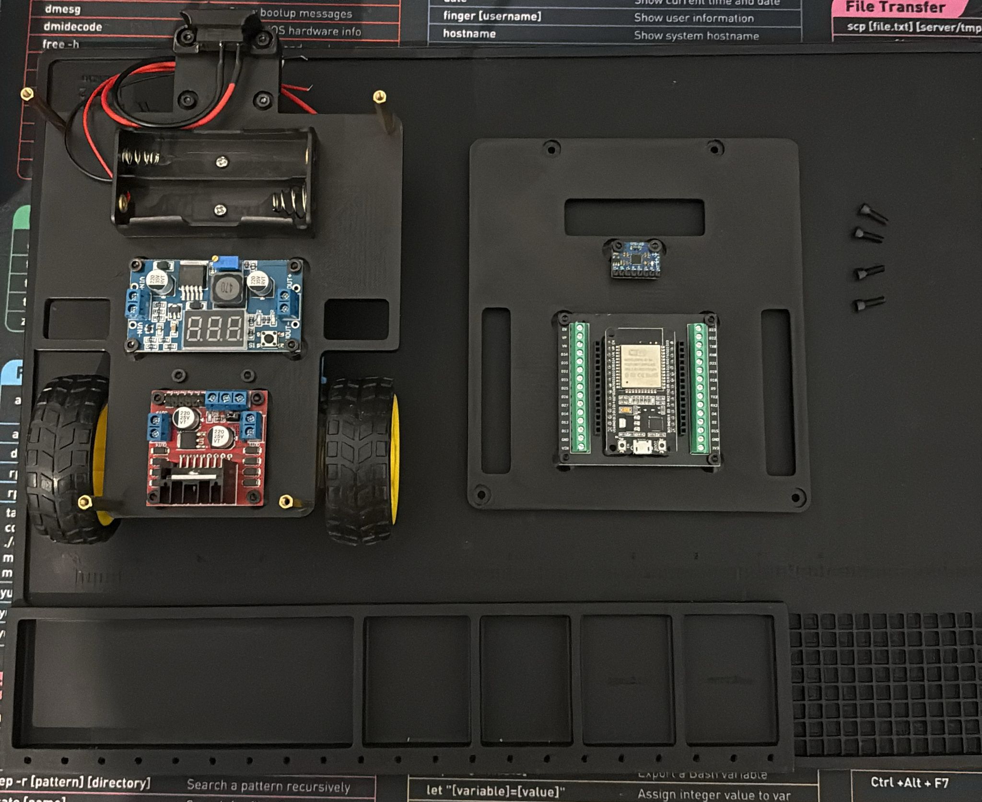
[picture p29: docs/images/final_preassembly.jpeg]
Both halves before joining


<p>
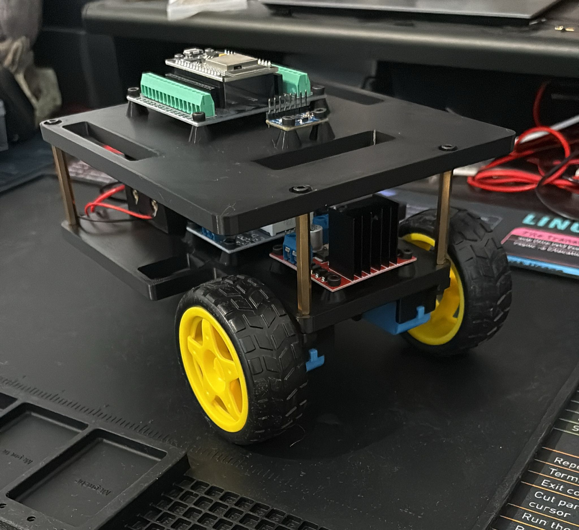
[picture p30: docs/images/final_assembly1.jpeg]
Final assembly front view

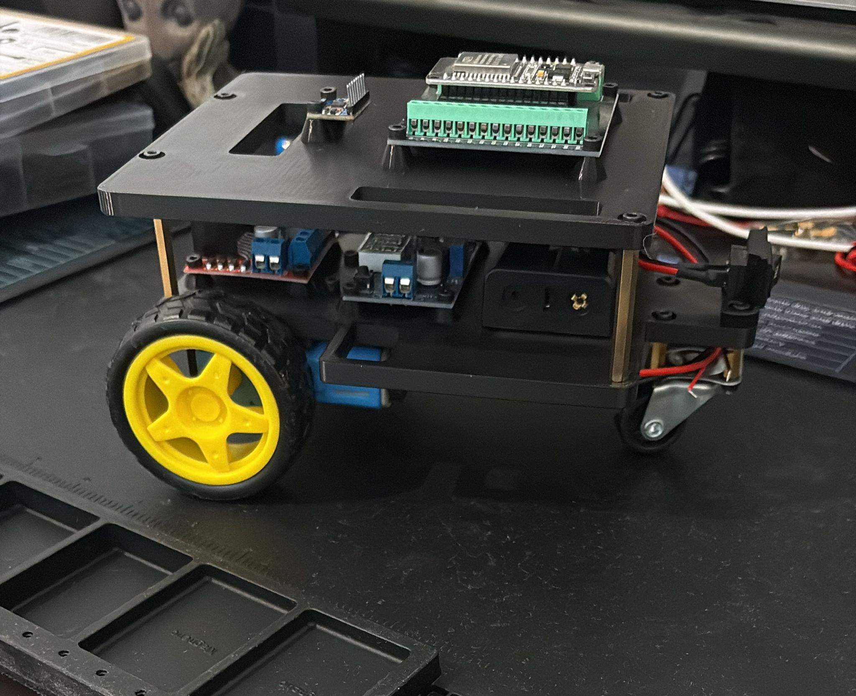
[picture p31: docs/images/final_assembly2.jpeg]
Final assembly side view

</p>

## Done!

Next steps:

1. **[Wiring Guide](wiring.md)** - Connect all the electrical components
2. **[Firmware Setup](firmware-setup.md)** - Flash micro-ROS onto the ESP32
3. **[ROS2 Setup](ros2-setup.md)** - Start driving!

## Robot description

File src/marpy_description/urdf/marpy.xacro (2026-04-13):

<?xml version="1.0"?>
<robot xmlns:xacro="http://www.ros.org/wiki/xacro" name="marpy">

  <xacro:include filename="$(find marpy_description)/urdf/materials.xacro" />
  <xacro:include filename="$(find marpy_description)/urdf/marpy_gazebo.xacro" />

  <!-- ==================== Properties ==================== -->
  <!-- Wheel geometry (from CLAUDE.md specs) -->
  <xacro:property name="wheel_radius" value="0.033" />
  <xacro:property name="wheel_separation" value="0.116" />  <!-- 2 * 0.058 -->

  <!-- ==================== base_footprint ==================== -->
  <!-- Ground-plane frame - sits at the contact point of the wheels -->
  <link name="base_footprint" />

  <joint name="base_joint" type="fixed">
    <parent link="base_footprint" />
    <child link="base_link" />
    <origin xyz="0 0 0.04825" rpy="0 0 0" />
  </joint>

  <!-- ==================== base_link ==================== -->
  <link name="base_link">
    <inertial>
      <origin xyz="-0.006324 -9.655e-06 0.029104" rpy="0 0 0" />
      <mass value="0.370" />
      <inertia ixx="0.000410" ixy="-3.76e-08" ixz="-5.34e-07" iyy="0.000657" iyz="-1.72e-08" izz="0.001058" />
    </inertial>
    <visual>
      <origin xyz="0 0 0" rpy="0 0 0" />
      <geometry>
        <mesh filename="package://marpy_description/meshes/base_link.STL" />
      </geometry>
      <material name="light_blue" />
    </visual>
    <collision>
      <origin xyz="0 0 0" rpy="0 0 0" />
      <geometry>
        <mesh filename="package://marpy_description/meshes/base_link.STL" />
      </geometry>
    </collision>
  </link>

  <!-- ==================== imu_link ==================== -->
  <link name="imu_link">
    <inertial>
      <origin xyz="-0.002055 -8.047e-05 0.000508" rpy="0 0 0" />
      <mass value="0.000548" />
      <inertia ixx="1.944e-08" ixy="-3.334e-11" ixz="8.066e-11" iyy="8.684e-09" iyz="-4.442e-11" izz="2.648e-08" />
    </inertial>
    <visual>
      <origin xyz="0 0 0" rpy="0 0 0" />
      <geometry>
        <mesh filename="package://marpy_description/meshes/imu_link.STL" />
      </geometry>
      <material name="dark_grey" />
    </visual>
    <collision>
      <origin xyz="0 0 0" rpy="0 0 0" />
      <geometry>
        <mesh filename="package://marpy_description/meshes/imu_link.STL" />
      </geometry>
    </collision>
  </link>

  <joint name="imu_joint" type="fixed">
    <parent link="base_link" />
    <child link="imu_link" />
    <origin xyz="0.024 0 0.0705" rpy="0 0 0" />
  </joint>

  <!-- ==================== left_wheel ==================== -->
  <link name="left_wheel">
    <inertial>
      <origin xyz="0 0.000627 0" rpy="0 0 0" />
      <mass value="0.167" />
      <inertia ixx="6.73e-05" ixy="0" ixz="0" iyy="1.132e-04" iyz="0" izz="6.73e-05" />
    </inertial>
    <visual>
      <origin xyz="0 0 0" rpy="0 0 0" />
      <geometry>
        <mesh filename="package://marpy_description/meshes/left_wheel.STL" />
      </geometry>
      <material name="dark_grey" />
    </visual>
    <collision>
      <origin xyz="0 0 0" rpy="${pi/2} 0 0" />
      <geometry>
        <cylinder radius="${wheel_radius}" length="0.025" />
      </geometry>
    </collision>
  </link>

  <joint name="left_wheel_joint" type="continuous">
    <parent link="base_link" />
    <child link="left_wheel" />
    <origin xyz="0.05725 0.058 -0.01525" rpy="0 0 0" />
    <axis xyz="0 1 0" />
    <limit effort="10" velocity="10" />
    <dynamics damping="0.5" friction="0.3" />
  </joint>

  <!-- ==================== right_wheel ==================== -->
  <link name="right_wheel">
    <inertial>
      <origin xyz="0 -0.000627 0" rpy="0 0 0" />
      <mass value="0.167" />
      <inertia ixx="6.73e-05" ixy="0" ixz="0" iyy="1.132e-04" iyz="0" izz="6.73e-05" />
    </inertial>
    <visual>
      <origin xyz="0 0 0" rpy="0 0 0" />
      <geometry>
        <mesh filename="package://marpy_description/meshes/right_wheel.STL" />
      </geometry>
      <material name="dark_grey" />
    </visual>
    <collision>
      <origin xyz="0 0 0" rpy="${pi/2} 0 0" />
      <geometry>
        <cylinder radius="${wheel_radius}" length="0.025" />
      </geometry>
    </collision>
  </link>

  <joint name="right_wheel_joint" type="continuous">
    <parent link="base_link" />
    <child link="right_wheel" />
    <origin xyz="0.05725 -0.058 -0.01525" rpy="0 0 0" />
    <axis xyz="0 1 0" />
    <limit effort="10" velocity="10" />
    <dynamics damping="0.5" friction="0.3" />
  </joint>

  <!-- ==================== caster_wheel ==================== -->
  <link name="caster_wheel">
    <inertial>
      <origin xyz="-0.008514 -0.000584 -0.01544" rpy="0 0 0" />
      <mass value="0.007" />
      <inertia ixx="4.87e-07" ixy="-2.84e-09" ixz="-2.58e-08" iyy="5.86e-07" iyz="-7.11e-10" izz="6.29e-07" />
    </inertial>
    <visual>
      <origin xyz="0 0 0" rpy="0 0 0" />
      <geometry>
        <mesh filename="package://marpy_description/meshes/caster_wheel.STL" />
      </geometry>
      <material name="dark_grey" />
    </visual>
    <collision>
      <origin xyz="0 0 -0.01425" rpy="0 0 0" />
      <geometry>
        <sphere radius="0.019" />
      </geometry>
    </collision>
  </link>

  <joint name="caster_wheel_joint" type="fixed">
    <parent link="base_link" />
    <child link="caster_wheel" />
    <origin xyz="-0.09775 0 -0.015" rpy="0 0 0" />
  </joint>

</robot>

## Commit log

2026-04-08 Initial commit: MERPY robot workspace
    Docs (BOM, assembly, wiring, firmware setup, ROS2 setup), teleop node,
    Docker setup with micro-ROS agent, and CI/CD pipeline.
2026-04-08 Add 3D printable STL files and update BOM
    7 STL parts: base plate, top plate, left/right motor mounts,
    switch mount, camera mount, and ESP32-CAM case.
    [ESP32_cam_case.stl, Merpy_base_plate.STL, Merpy_cam_mount.STL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]
2026-04-08 Add rendered wiring diagram
    Color-coded diagram with component blocks, pin labels, wire legend,
    and notes. ASCII version kept as collapsible fallback.
2026-04-08 Fix wiring diagram to show all 6 wires per motor
    Each motor now shows: Motor +/-, Encoder VCC, Encoder GND,
    Encoder Ch A, Encoder Ch B. 5V and GND lines routed from
    buck converter to both encoder VCC/GND pins.
2026-04-08 Update ASCII wiring diagram to show all 6 motor wires
    Now includes encoder VCC/GND per motor and clearer layout
    matching the rendered diagram.
2026-04-08 Add EasyEDA schematic to wiring guide
    Full circuit schematic showing ESP32, L298N, motors with encoders,
    buck converter, battery, and ESP32-CAM.
2026-04-08 Crop title block from schematic image
2026-04-08 Update schematic image with cleaner version
2026-04-08 Remove ASCII wiring diagram
    Rendered diagram and EasyEDA schematic are sufficient.
2026-04-08 Match diagram widths and remove CI/CD workflow
    Set both wiring images to same width. Removed .github/workflows
    as CI is not needed for this repo.
2026-04-09 Add merpy_description and merpy_bringup packages, remove teleop_control_node
    Replace the old teleop_control_node with proper robot description (URDF/xacro)
    and bringup (launch files) packages. Wheel colors set to black to match the
    caster wheel.
    [caster_wheel.STL, empty.sdf, left_wheel.STL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]
2026-04-09 Rename MERPY to MARPY (Most Affordable ROS2 Platform Yet)
    Fix "Effordable" typo to "Affordable", rename all packages,
    directories, files, and references from merpy to marpy.
    [caster_wheel.STL, empty.sdf, left_wheel.STL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]
2026-04-09 Update banner image and rename CAD STL files to Marpy
    Regenerate banner with corrected "MARPY - Most Affordable ROS2 Platform Yet"
    text. Rename all Merpy_*.STL files in CAD/ to Marpy_*.STL.
    [Marpy_base_plate.STL, Marpy_cam_mount.STL, Marpy_left_TT_motor_mount.STL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]
2026-04-09 Add marpy_localization package for wheel odometry
    New package computes differential-drive odometry from /joint_states
    and publishes /odom + odom->base_footprint TF. Used by both sim and
    real hardware so the data pipeline is identical.
    - Remove odom/tf publishing from Gazebo DiffDrive plugin
    - Add odometry_node to both sim.launch.py and real.launch.py
    - Add marpy_localization dependency to marpy_bringup
    [marpy_gazebo.xacro]
2026-04-09 Add odometry path publishing, simulation docs, and update repo structure
    Odometry node now publishes /odom_path (nav_msgs/Path) to visualize the
    robot's traveled route in RViz. Added simulation setup guide and updated
    README with marpy_localization package and new topics.
2026-04-13 Remove CAD STLs (moved to MakerWorld), add IMU support, and rewrite assembly docs
    - Remove CAD/ folder, point all references to MakerWorld and Printables
    - Add IMU link/joint to URDF from updated SolidWorks export
    - Add Gazebo IMU sensor plugin (50 Hz) and gz_bridge topic
    - Update meshes from new SolidWorks export
    - Rewrite assembly.md with real photos, hardware tables, and step-by-step flow
    - Split docs: assembly (mechanical only), wiring (electrical), firmware (flashing)
    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
    [ESP32_cam_case.stl, Marpy_base_plate.STL, Marpy_cam_mount.STL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]
2026-04-13 Add ESP32 mounting and final assembly steps with photos
2026-04-13 Add Printables link in BOM note and tune Gazebo physics for smoother stops
    - Link ESP32-CAM GoPro case in BOM note
    - Reduce contact stiffness, increase contact/joint damping
    - Add deceleration limits to diff drive plugin
    [marpy.xacro, marpy_gazebo.xacro]
2026-04-14 Update wiring docs with correct motor wire colors, add MPU6050 IMU section, and consolidate ROS2 topics
    - Fix motor wire table to match actual wire colors (M+ red, M- blue, VCC green, GND black, C1 yellow, C2 white)
    - Add MPU6050 IMU wiring section (I2C on GPIO 16/17)
    - Add battery back-feed safety warning
    - Move ROS2 topics table from README to ros2-setup.md
    - Add RViz launch to quick reference
2026-04-14 Change IMU I2C pins from GPIO 16/17 to GPIO 13/15
    GPIO 16/17 may conflict with internal flash on ESP32-WROVER modules.
    GPIO 13/15 are safe on all ESP32 variants.
2026-04-14 Update BOM with correct Amazon links, add MPU6050, and match assembly hardware
    - Replace broken Amazon links with working ones
    - Add MPU6050 IMU to electronics list
    - Split out TT motor wheels as separate item
    - ESP32 now includes screw terminal breakout board
    - Update hardware/fasteners to match assembly instructions
    - Update component descriptions to match actual products
2026-04-14 Add optional ESP32-CAM to BOM and renumber items
2026-04-26 Edit wiring.md file
2026-04-26 Stamp odom TF with /joint_states header so the TF chain stays coherent
    odometry_node was timestamping odom->base_footprint with the host clock
    while robot_state_publisher rebroadcasts wheel TFs at the firmware
    stamp from /joint_states. Mixing two clocks made RViz render the wheels
    detaching from base_link and snapping back as fresh samples landed.
    Reusing the message stamp puts both halves of the chain on one timeline,
    matching what diff_drive_controller does within ros2_control.
2026-04-26 Move agent-discovery troubleshooting tip from firmware-setup to ros2-setup
    The EN-reset workaround for "ESP32 stuck waiting for agent" is a
    runtime/usage issue (agent started after the ESP32), so it belongs in
    the ros2-setup verification section, not the firmware flashing guide.
2026-04-26 Add real-robot launch step to Drive section, mention IMU in firmware blurb
    Inserts a Terminal 2 entry that runs marpy_bringup real.launch.py
    (robot_state_publisher, odometry_node, RViz) and bumps teleop to
    Terminal 3. Also notes that marpy_firmware now publishes IMU readings
    alongside motor control and encoders.
2026-04-26 Drop em-dashes from odometry_node comments per repo style
2026-04-27 Update firmware-setup guide for base/cam restructure
    Reflect the marpy_firmware split into base/ and cam/ PlatformIO
    projects: prefix wifi_config.h paths with base/, switch CLI commands
    to `pio run -d base ...`, and note the new optional cam/ vision
    firmware.
2026-04-28 Add marpy_cam_bridge: ESP32-CAM MJPEG -> sensor_msgs/Image
    The cam firmware no longer publishes ROS topics directly (see
    marpy_firmware commit). Instead it serves an MJPEG stream over HTTP at
    http://marpy-cam.local:81/stream. This package's mjpeg_bridge node uses
    cv2.VideoCapture to consume that stream and republish raw frames as
    sensor_msgs/Image on /camera/image_raw.
    Bridge has params for stream_url, topic, frame_id, and reconnect delay.
    It runs the cv2 read loop on a daemon thread and keeps reconnecting on
    network errors so the node stays up while the cam reboots / Wi-Fi flaps.
    real.launch.py now starts the bridge alongside RViz/odometry, and the
    shared display.rviz config includes an I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
2026-04-28 marpy_cam_bridge: add rotate_deg param, default 90 CCW
    The ESP32-CAM is physically mounted rotated on the robot. Doing the
    rotation in the bridge means downstream consumers (RViz, perception
    nodes) see a correctly oriented image regardless of how the cam is
    mounted.
    Param values: 0 (none), 90 (CCW, default), 180, 270 (CW). Override
    with --ros-args -p rotate_deg:=0 if the cam mounting changes.
2026-05-03 bringup: use mDNS for cam stream URL
    Switching APs (GL.iNet to phone hotspot) reshuffles the cam IP,
    so prefer marpy-cam.local. The -p stream_url:=http://<ip>:81/stream
    override stays as the escape hatch for networks without mDNS.
2026-05-03 marpy_cam_bridge: replace cv2.VideoCapture with requests-based MJPEG parser
    OpenCV's videoio backends do not reliably handle multipart/x-mixed-replace:
    on this setup it falls through to the CAP_IMAGES file-glob backend and
    fails to open the URL at all, while leaving the TCP socket lingering. The
    cam's httpd has only ~7 worker slots, so a few failed retries wedged it
    for every other client (including a browser).
    The new implementation streams the response with requests.get(stream=True),
    parses the multipart envelope by hand, and decodes JPEGs with cv2.imdecode.
    Sockets are force-closed on every error path (Response.__exit__ tries to
    drain the body first, which on a broken chunked stream sile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
2026-05-03 README: clarify the WiFi requirement, mention phone hotspot
    The ESP32 needs 2.4 GHz, and a mobile phone hotspot (verified on iOS) is
    a perfectly reasonable way to provide it.
2026-05-05 README: add real and sim demo videos
    Embed YouTube thumbnails (cropped to remove YouTube's side bars)
    linking out to the real-robot and Gazebo demo videos. Also tighten
    the Contributing line.

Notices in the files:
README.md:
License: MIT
